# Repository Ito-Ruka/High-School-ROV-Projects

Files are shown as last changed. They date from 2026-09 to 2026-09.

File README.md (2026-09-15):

# High-Current ESC Carrier & Power Distribution Board

<p align="center">
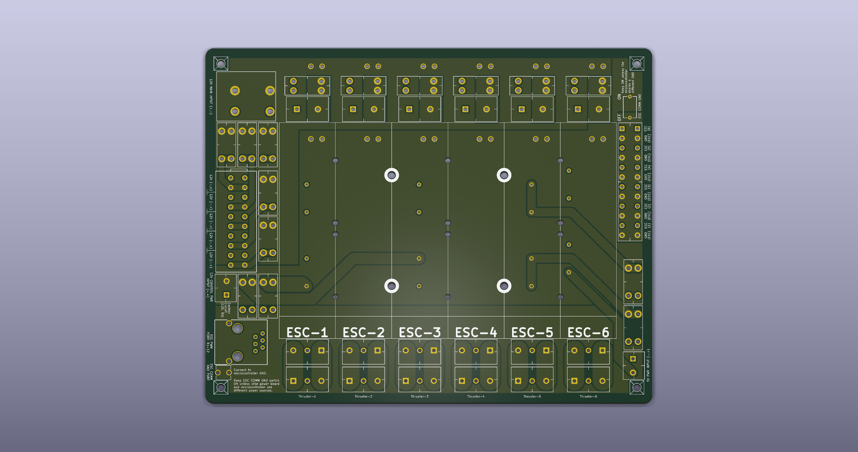
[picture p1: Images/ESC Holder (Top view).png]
ESC Holder Board Top View
  
</p>

<p align="center">
  <em>A dedicated power distribution and signal routing carrier designed for Blue Robotics Basic ESCs driving T200 Thrusters.</em>
</p>

---

### Overview

This carrier board consolidates discrete motor controllers into an integrated, serviceable module inside tight electronics enclosures. It pairs high-current DC bus routing with low-noise signal channels to eliminate wire harness congestion and streamline thruster maintenance.

* **Primary Application:** Power distribution and PWM signal breakout for up to 6 external ESCs
* **Target Hardware:** Blue Robotics Basic ESC / T200 Thruster systems
* **Design Toolchain:** KiCad 10.0 Native

---

### Key Architectural Features

* **Integrated ESC Mounting:** Mechanically aligns and retains up to 6 discrete ESC modules into a rigid, compact frame.
* **Optimized Thermal Spreading:** Heavy copper planes provide massive thermal mass and heat dissipation across the substrate during sustained loads.
* **Clean Harness Management:** Groups power taps and signal headers to decouple propulsion wiring from sensitive telemetry lines.
* **Dedicated Auxiliary Port:** Supplies clean parallel DC power for onboard sensors, logic, or auxiliary payloads.

---

### Visual Reference

<table>
  <tr>
    <td width="50%" align="center">
      Top-down 2D trace routing view
      <br><strong>Top Layer & Component Layout</strong>
    </td>
    <td width="50%" align="center">
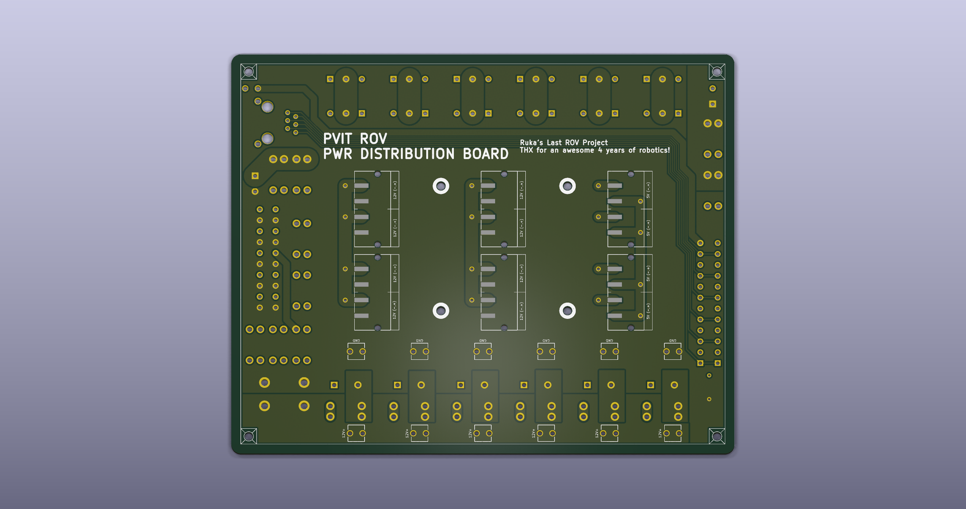
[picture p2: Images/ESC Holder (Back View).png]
Back view ground plane and routing
      
      <br><strong>Bottom Layer & Ground Plane</strong>
    </td>
  </tr>
</table>

---

### Electrical & Mechanical Specifications

| Parameter | Specification | Design Notes |
| :--- | :--- | :--- |
| **Operating Voltage** | 12 V DC | Nominal battery bus input |
| **Max Continuous Current** | 20 A total | Sized for sustained multi-thruster runs |
| **Per-Channel Allocation** | 3 A per ESC channel | Dedicated rail routing for 6 ESC positions |
| **Auxiliary Power Rail** | 2 A continuous capacity | Dedicated breakout for accessories/sensors |
| **Board Dimensions** | 159 mm × 128 mm × 1.6 mm | Landscape $(W \times H \times T)$ footprint |
| **Layer Count** | 2-Layer FR4 | Standard fab; aluminum backing compatible |
| **Copper Weight** | 15 oz/ft² ($525\ \mu\text{m}$) | Extreme heavy copper power distribution |

---

### Fabrication & Assembly Notes (15 oz Copper)
* **Etch Clearance:** Minimum trace clearance and spacing set to $\ge 1.2\text{ mm}$ ($50\text{ mil}$) to prevent shorts from chemical undercut during $525\ \mu\text{m}$ copper etching.

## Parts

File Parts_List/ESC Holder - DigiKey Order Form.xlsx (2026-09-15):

 | DigiKey
 | Quantity | Part Number (Digi Key) | Link | Description | Unit Price | Extended Price USD
FALSE | 20 | 102-6135-ND | https://www.digikey.com/en/products/detail/same-sky-formerly-cui-devices/TB001-500-03BE/10064059 | TERMINAL BLOCK, SCREW TYPE, 5.00 | $0.48 | $9.52
FALSE | 20 | 102-6145-ND | https://www.digikey.com/en/products/detail/same-sky-formerly-cui-devices/TB002-500-02BE/10064069 | TERMINAL BLOCK, SCREW TYPE, 5.00 | $0.31 | $6.12
FALSE | 6 | 1297-1110-1-ND | https://www.digikey.com/en/products/detail/würth-elektronik/691709710304/4725707?s=N4IgTCBcDaIIxgJwHYC0cMAZ2oHIBEQBdAXyA | TERM BLK 4POS SIDE ENTRY 5MM SMD | $5.25 | $31.50
FALSE | 6 | 1297-1109-1-ND | https://www.digikey.com/en/products/detail/würth-elektronik/691709710303/4725704?s=N4IgTCBcDaIIxgJwHYC0c4AZHtQOQBEQBdAXyA | TERM BLK 3POS SIDE ENTRY 5MM SMD | $3.87 | $23.22
FALSE | 2 | 102-TBLH10V-350-12BK-ND | https://www.digikey.com/en/products/detail/same-sky-formerly-cui-devices/TBLH10V-350-12BK/10442015 | TERMINAL BLOCK, SCREWLESS, HIGH | $4.60 | $9.20
FALSE | 6 | A31435-ND | https://www.digikey.com/en/products/detail/te-connectivity-amp-connectors/5555140-1/769579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 | CONN MOD JACK 6P6C R/A SHIELDED | $1.88 | $11.28
FALSE | 10 | 36-3568-15-ND | https://www.digikey.com/en/products/detail/keystone-electronics/3568-15/9921800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 | FUSE SOCKET (BLUE) | $1.00 | $9.97
FALSE | 6 | CKC5106-ND | https://www.digikey.com/en/products/detail/c-k/L101011MS02Q/484142?s=N4IgTCBcDaIMIGk4FYCMAGAbAWgHIBEQBdAXyA | SWITCH SLIDE SPST 4A 125V | $3.53 | $21.18
FALSE | 4 | Z5195-ND | https://www.digikey.com/en/products/detail/omron-electronics-inc-emc-div/A6TN-1104/2754763 | SWITCH SLIDE DIP SPST 0.025A 24V | $0.96 | $3.84
FALSE | 4 | 2946-2606-1102-ND | https://www.digikey.com/en/products/detail/wago-corporation/2606-1102/15575098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 | PCB TERMINAL BLOCK; LEVER; 6 MM; | $7.11 | $28.44
FALSE | 10 | 1297-1108-1-ND | https://www.digikey.com/en/products/detail/würth-elektronik/691709710302/4725701 | TERM BLK 2POS SIDE ENTRY 5MM SMD | $2.64 | $26.39
FALSE | 2 | 1849-1250-ND | https://www.digikey.com/en/products/detail/metz-connect-usa-inc/360410/9462530 | TERM BLOCK 1POS SIDE ENTRY PCB | $0.80 | $1.60
 |  |  |  |  | SUM: | $182.26

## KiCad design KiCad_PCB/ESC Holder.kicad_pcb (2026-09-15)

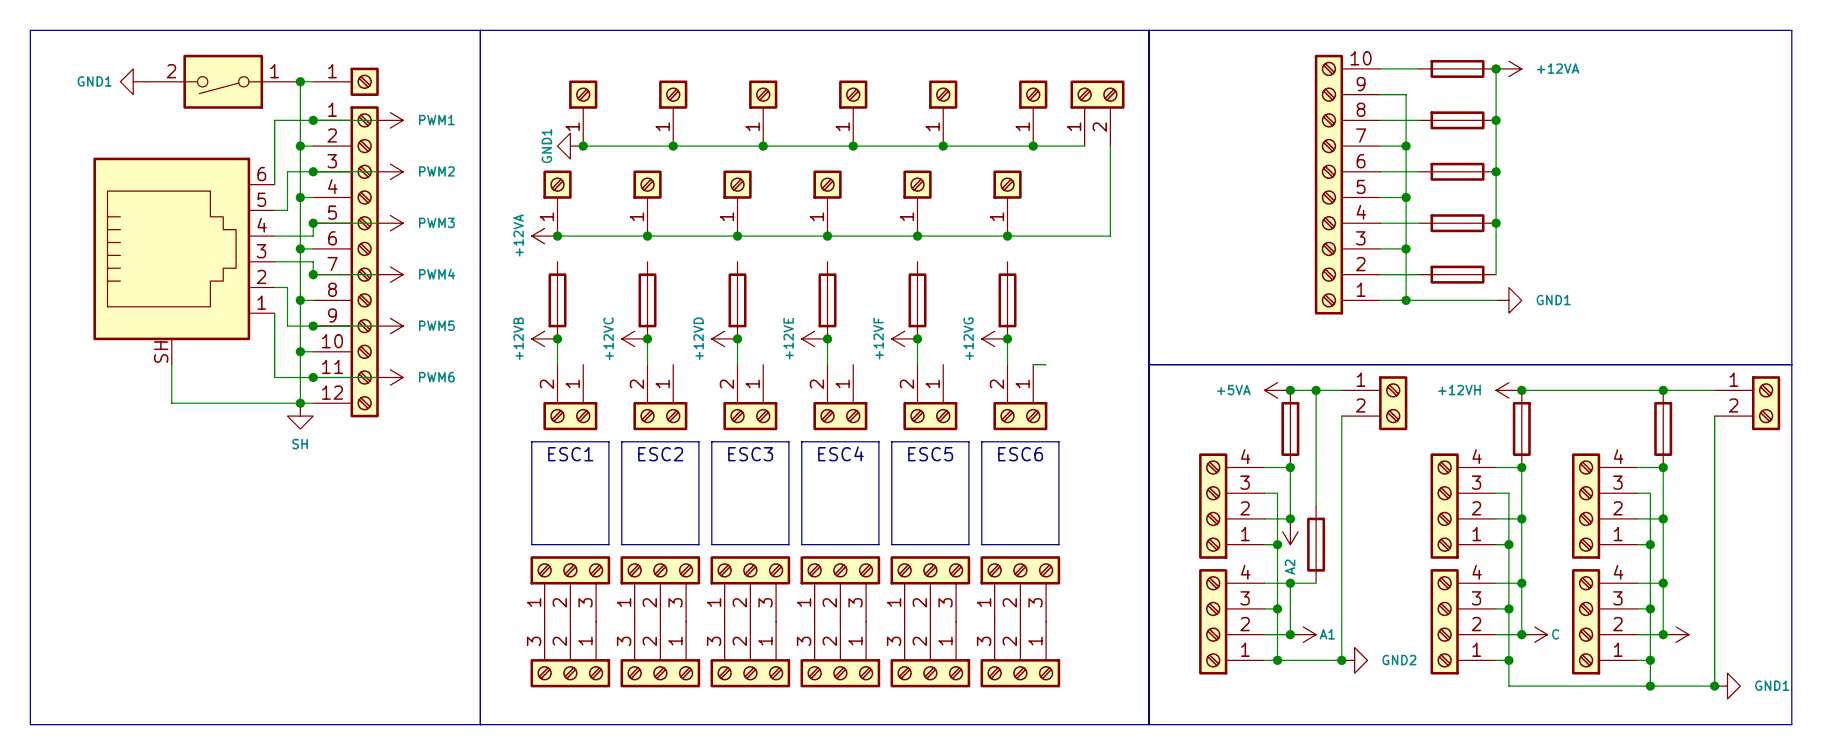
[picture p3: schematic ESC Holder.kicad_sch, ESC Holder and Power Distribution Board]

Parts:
F1, F2, F3, F4, F5, F6, F7, F8, F9, F10, F11, F12, F13, F14, F15: Fuse; Fuse Holder 30 A 500V 1 Circuit Blade (FUSE_3568-15)
J1, J6, J9, J12, J15, J18, J22, J28, J43: Screw_Terminal_01x02; 2 Position Wire to Board Terminal Block Horizontal with Boa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
J2, J3, J4, J5, J7, J8, J10, J11, J13, J14, J16, J17: Screw_Terminal_01x03; 3 Position Wire to Board Terminal Block Horizontal with Boa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
J19: RJ12_Shielded; Jack Modular Connector 6p6c (RJ11, RJ12, RJ14, RJ25) 90° An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
J20: Screw_Terminal_01x10; 10 Position Wire to Board Terminal Block Horizontal with Bo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
J21, J27, J29, J30, J31, J32, J33, J34, J35, J36, J37, J38, J39: Screw_Terminal_01x01; 1 Position Wire to Board Terminal Block Horizontal with Boa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
J23, J25, J26, J40, J41, J42: Screw_Terminal_01x04; TERM BLK 4POS SIDE ENTRY 5MM SMD (CONN4_710304_WRE)
J24: Screw_Terminal_01x12; 12 Position Wire to Board Terminal Block Vertical with Boar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
SW1: SW_DIP_x01; SWITCH SLIDE DIP SPST 0.025A 24V (SW_A6TN-1104_OMR)

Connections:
+5VA: F12.2, F15.2, J43.1
+12VA: F2.1, F3.1, F4.1, F5.1, F9.1, J21.1, J22.2, J29.1, J30.1, J31.1, J32.1, J33.1
+12VB: F10.2, J1.2
+12VC: F1.2, J6.2
+12VD: F11.2, J9.2
+12VE: F7.2, J12.2
+12VF: F8.2, J15.2
+12VG: F6.2, J18.2
+12VH: F13.2, F14.2, J28.1
A1: F15.1, J25.2, J25.4
A2: F12.1, J26.2, J26.4
B: F14.1, J41.2, J41.4, J42.2, J42.4
C: F13.1, J23.2, J23.4, J40.2, J40.4
GND1: J20.1, J20.3, J20.5, J20.7, J20.9, J22.1, J23.1, J23.3, J28.2, J34.1, J35.1, J36.1, J37.1, J38.1, J39.1, J40.1, J40.3, J41.1, J41.3, J42.1, J42.3, SW1.2
GND2: J25.1, J25.3, J26.1, J26.3, J43.2
unnamed: J2.1, J3.3
unnamed: J2.2, J3.2
unnamed: J2.3, J3.1
unnamed: J4.1, J5.3
unnamed: J4.2, J5.2
unnamed: J4.3, J5.1
unnamed: J7.1, J8.3
unnamed: J7.2, J8.2
unnamed: J7.3, J8.1
unnamed: J10.1, J11.3
unnamed: J10.2, J11.2
unnamed: J10.3, J11.1
unnamed: J13.1, J14.3
unnamed: J13.2, J14.2
unnamed: J13.3, J14.1
unnamed: J16.1, J17.3
unnamed: J16.2, J17.2
unnamed: J16.3, J17.1
unnamed: F4.2, J20.2
unnamed: F2.2, J20.4
unnamed: F9.2, J20.6
unnamed: F5.2, J20.8
unnamed: F3.2, J20.10
PWM1: J19.6, J24.1
PWM2: J19.5, J24.3
PWM3: J19.4, J24.5
PWM4: J19.3, J24.7
PWM5: J19.2, J24.9
PWM6: J19.1, J24.11
SH: J19.SH, J24.2, J24.4, J24.6, J24.8, J24.10, J24.12, J27.1, SW1.1

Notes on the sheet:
ESC4
ESC1
ESC3
ESC2
ESC6
ESC5

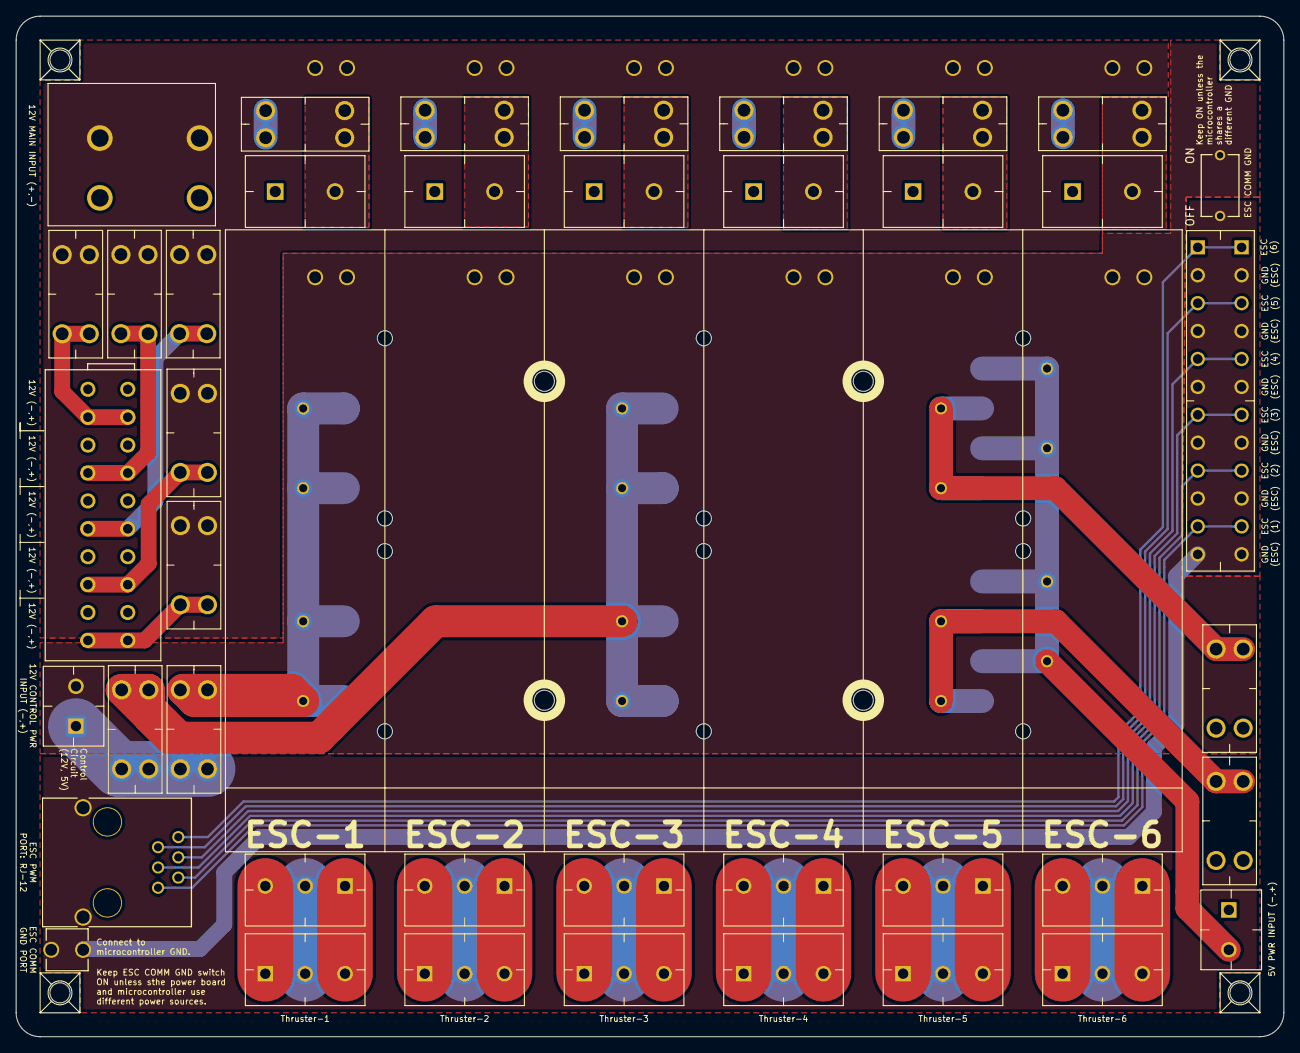
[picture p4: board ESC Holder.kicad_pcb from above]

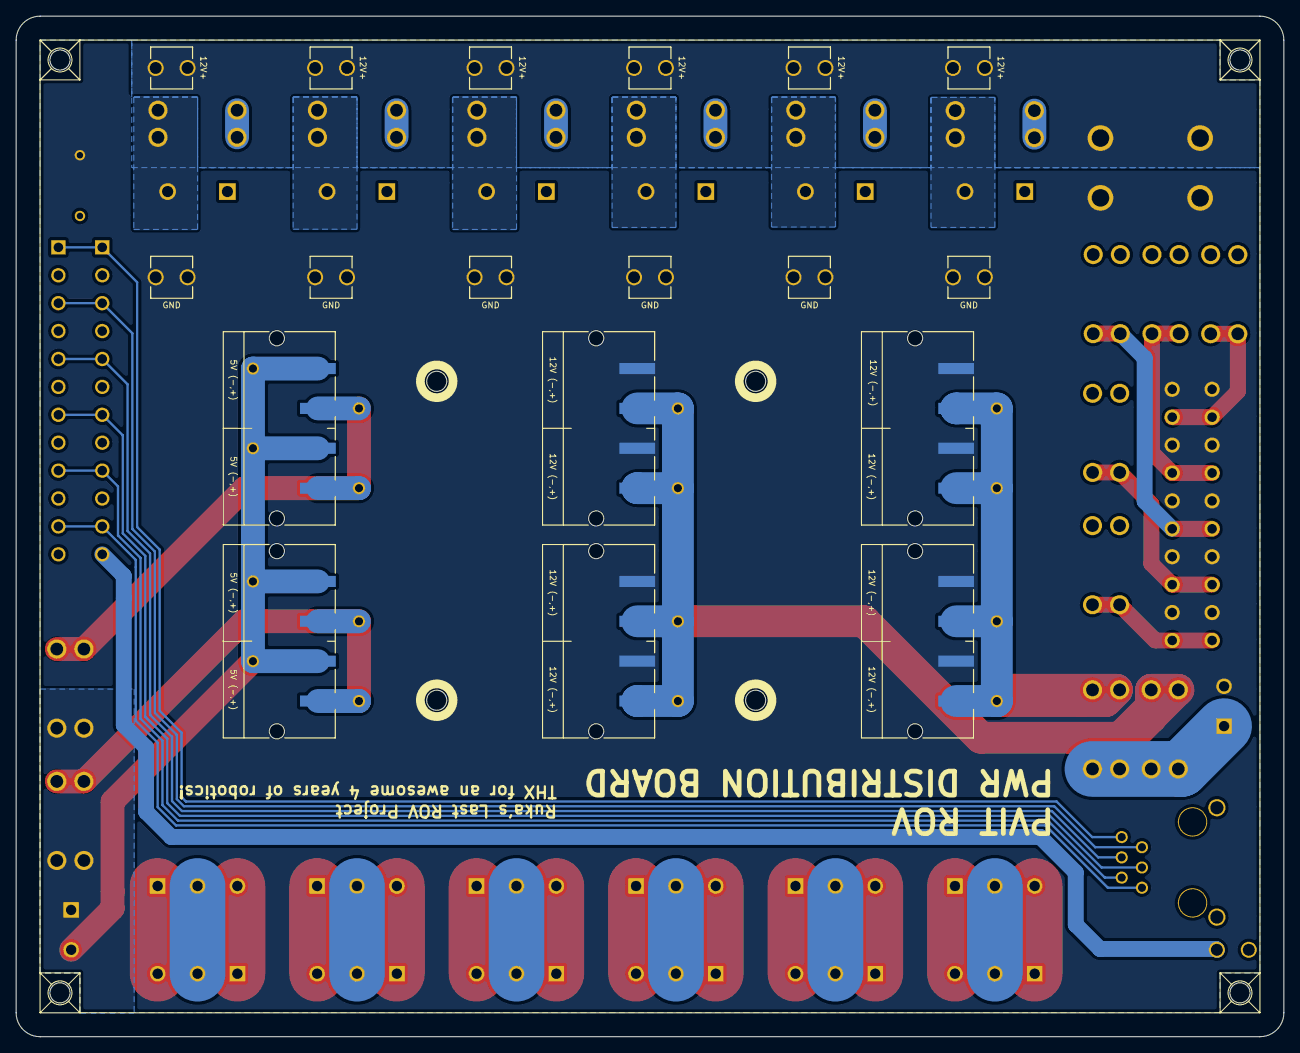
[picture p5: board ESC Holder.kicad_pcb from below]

Board: 2 copper layers, 159.0 x 128.0 mm, 59 parts (18 on the bottom side), 45 nets.

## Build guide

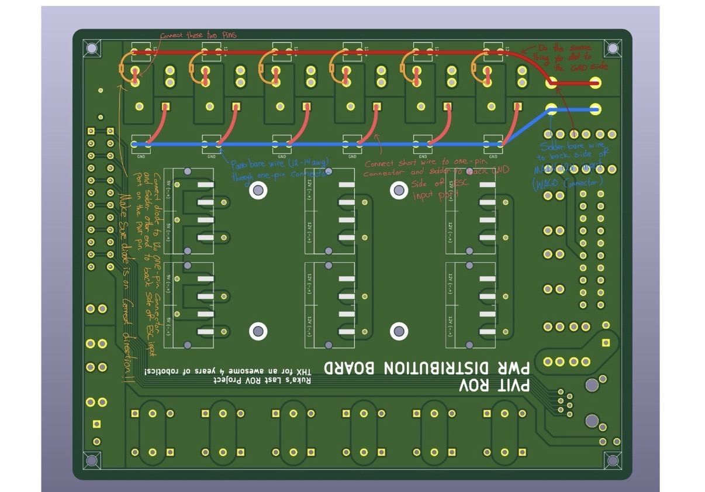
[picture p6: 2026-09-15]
Additional_Info/External_Wiring_Instructions.jpg

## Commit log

2026-09-15 Rename ESC Holder.kicad_pcb to ESC Holder.kicad_pcb
    [ESC Holder.kicad_pcb]
2026-09-15 Rename ESC Holder.kicad_pro to ESC Holder.kicad_pro
2026-09-15 Rename ESC Holder.kicad_sch to ESC Holder.kicad_sch
    [ESC Holder.kicad_sch]
2026-09-15 Rename ESC Holder (Top view).png to Images/ESC Holder (Top view).png
2026-09-15 Rename ESC Holder (Back View).png to Images/ESC Holder (Back View).png
